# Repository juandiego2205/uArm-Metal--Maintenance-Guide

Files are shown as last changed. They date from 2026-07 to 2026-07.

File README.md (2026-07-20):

# uArm Metal – Maintenance Guide Resources

<table>
<tr>
<td width="220" align="center">

uArm Metal

</td>
<td>

This repository contains the resources used to support the maintenance, calibration, and assembly of the **uArm Metal** robotic arm. It includes the original CAD files, assembly documentation, calibration tools, technical documents, and useful reference links required to work with the platform.

</td>
</tr>
</table>

## Repository Structure

```
uArm_Metal/
├── Assembly_Resources/
├── CAD_Files/
├── Calibration_Files/
├── Documentation/
├── Useful_Links.txt
└── README.md
```

### Assembly_Resources

Contains all resources related to the assembly of the robotic arm.

* Assembly manual
* Assembly videos

### CAD_Files

Contains the original mechanical design files of the uArm Metal.

* STEP files
* STL files
* Assembly files

These files can be used for visualization, modification, manufacturing, or replacement of mechanical components.

### Calibration_Files

Contains the files required to calibrate the robotic arm.

* Arduino calibration
* Calibration data (Excel)

The calibration code requires the official **UArmForArduino** library before compilation.

### Documentation

Contains technical documentation related to the uArm Metal.

Examples include:

* Technical documentation
* Additional reference documents

### Useful_Links.txt

Contains links to official resources and documentation, including:

* Official uArm Arduino library
* Official documentation
* Additional reference pages

## Requirements

To use the calibration software, install the official **UArmForArduino** library before compiling the Arduino project.

## Purpose

This repository serves as a centralized collection of resources for users who need to assemble, maintain, calibrate, repair, or study the **uArm Metal** robotic arm. It is intended to simplify access to all relevant documentation, software, CAD models, and supporting materials in a single location.

## License

The original files, documentation, and software remain subject to the licenses and copyrights of their respective authors. This repository organizes and references these materials for educational, maintenance, and research purposes.

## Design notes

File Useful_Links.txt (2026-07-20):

uArm Resources
===============

Official Arduino Library
https://github.com/uArm-Developer/UArmForArduino

uArm Metal Getting Started Guide
https://uarmdocs.readthedocs.io/getting_started/

Arduino Library Documentation
https://uarm-developer.github.io/UArmForArduino/

Description:
- Official Arduino library for the uArm Metal.
- User guide for hardware setup, calibration, and operation.
- API documentation and programming reference.

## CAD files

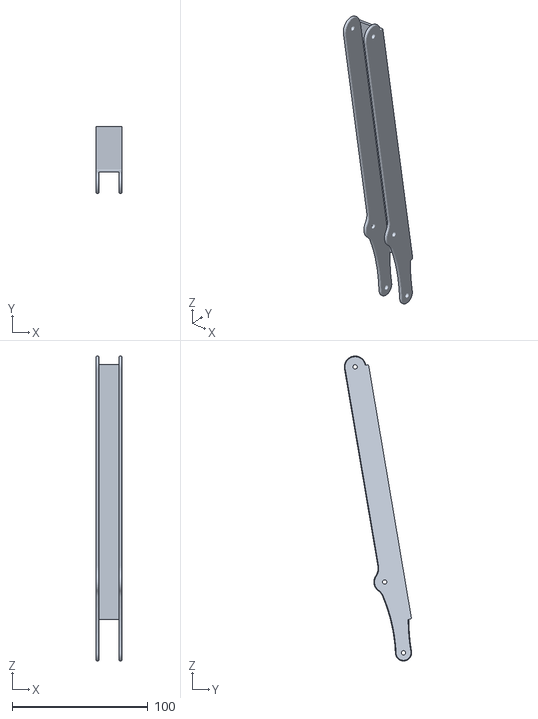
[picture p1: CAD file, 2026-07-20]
CAD_Files/STL_files_Uarm(metal)/Uarm metal 装配体 - U100002_ASM-1 U200004_ASM-1 U200004-1.STL
19.0 x 49.6 x 224.7

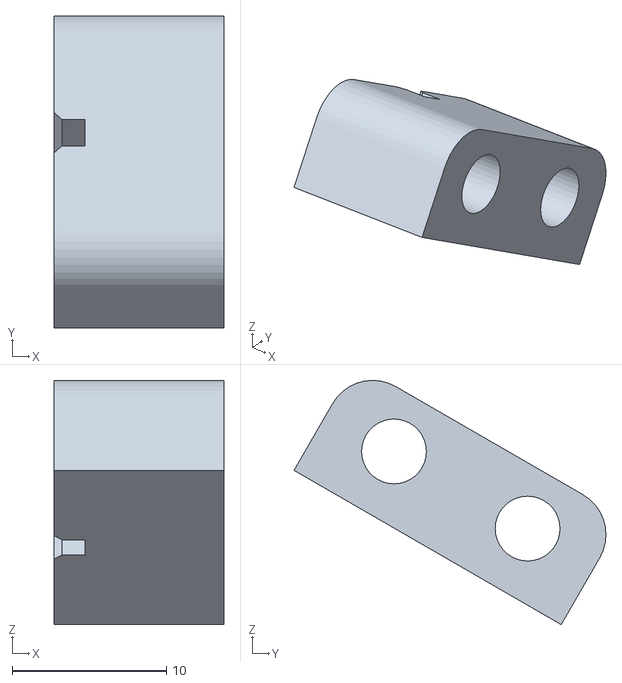
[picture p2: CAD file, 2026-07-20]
CAD_Files/STL_files_Uarm(metal)/Uarm metal 装配体 - U100002_ASM-1 U200040_ASM-1 U200040-1.STL
11.0 x 20.2 x 15.8

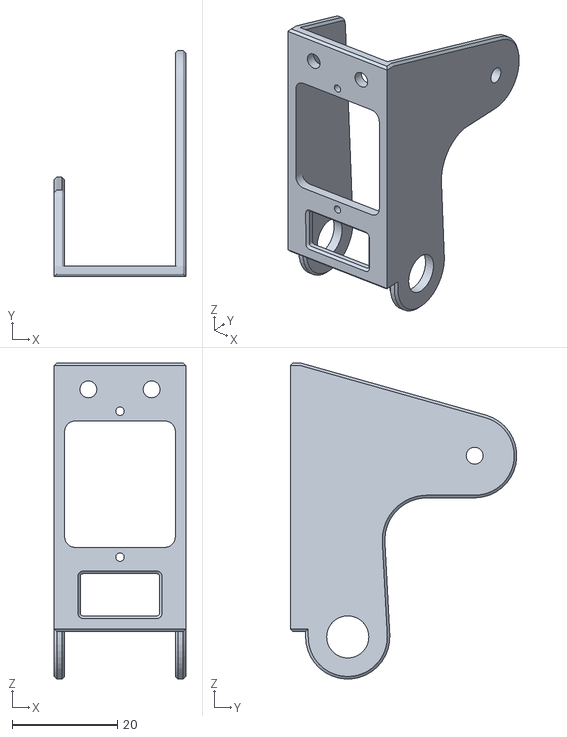
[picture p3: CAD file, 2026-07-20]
CAD_Files/STL_files_Uarm(metal)/Uarm metal 装配体 - U100002_ASM-1 U200003_ASM-1 U200003-1.STL
25.0 x 43.0 x 60.0

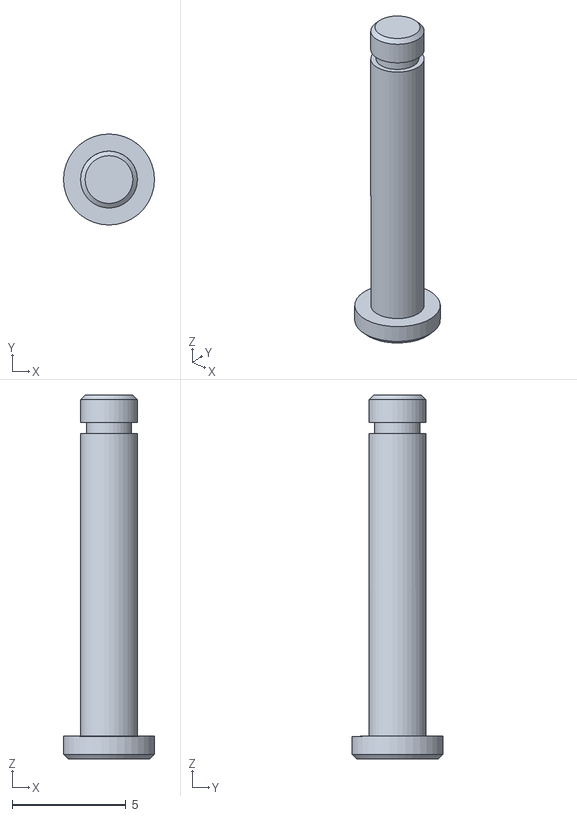
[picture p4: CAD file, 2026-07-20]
CAD_Files/STL_files_Uarm(metal)/Uarm metal 装配体 - U100004_ASM-1 U300004_ASM-1 U200036_ASM-1 U200036-1.STL
4.00 x 4.00 x 16.0

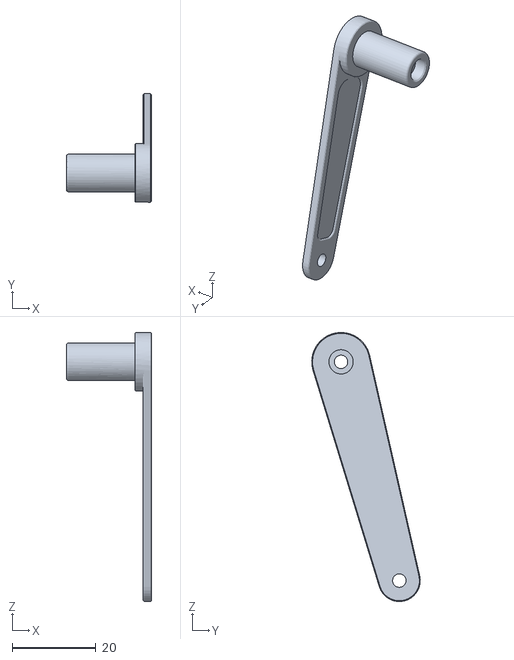
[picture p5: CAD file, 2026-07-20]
CAD_Files/STL_files_Uarm(metal)/Uarm metal 装配体 - U100002_ASM-1 U200067_ASM-1 U200067-1.STL
20.3 x 25.9 x 64.2

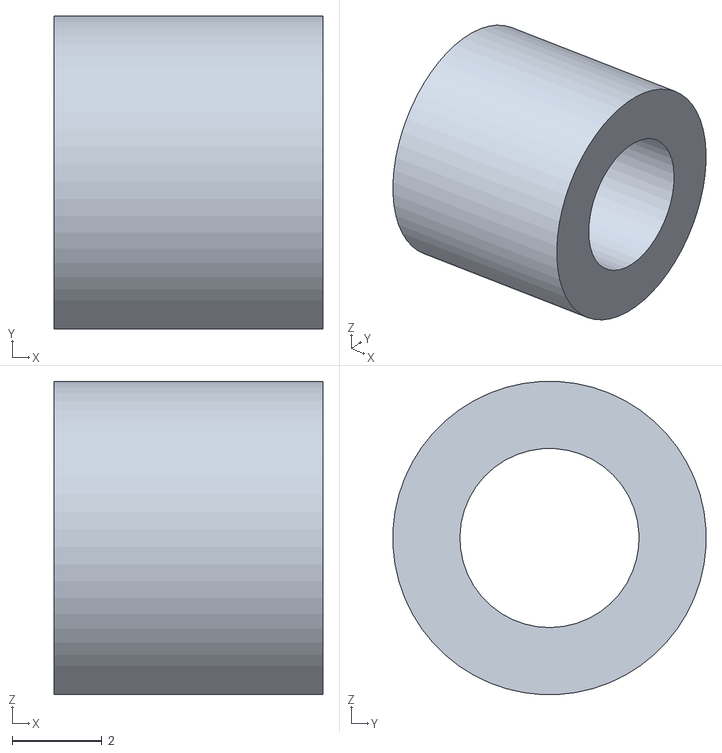
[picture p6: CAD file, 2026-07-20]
CAD_Files/STL_files_Uarm(metal)/Uarm metal 装配体 - U100002_ASM-1 U200020_ASM-1 U200020-1.STL
6.00 x 6.99 x 6.99

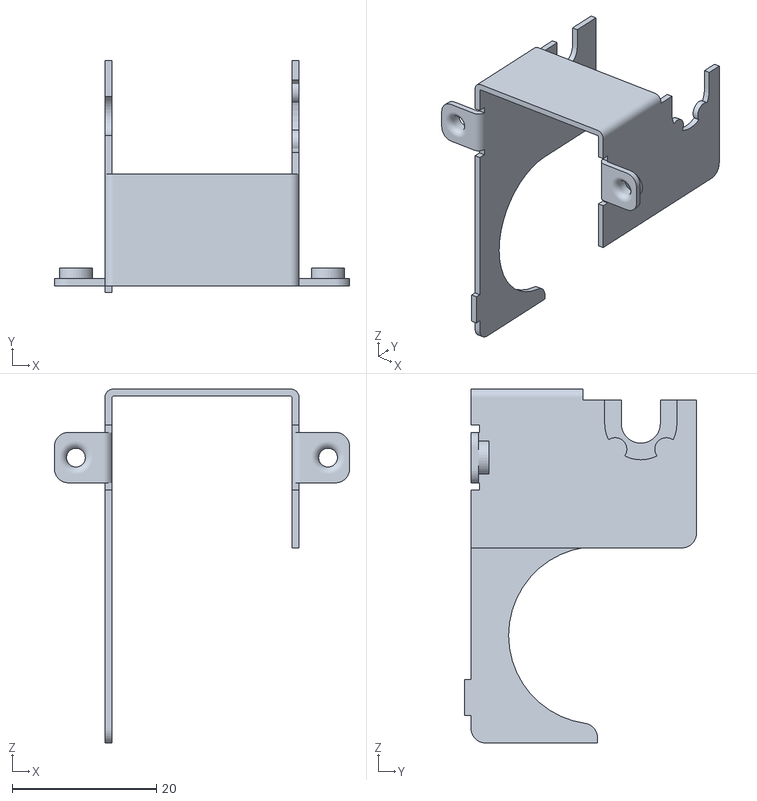
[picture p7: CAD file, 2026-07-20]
CAD_Files/STL_files_Uarm(metal)/Uarm metal 装配体 - U100003_ASM-1 U300002_ASM-1 U200030_ASM-1 U200030-1.STL
40.9 x 32.1 x 49.0

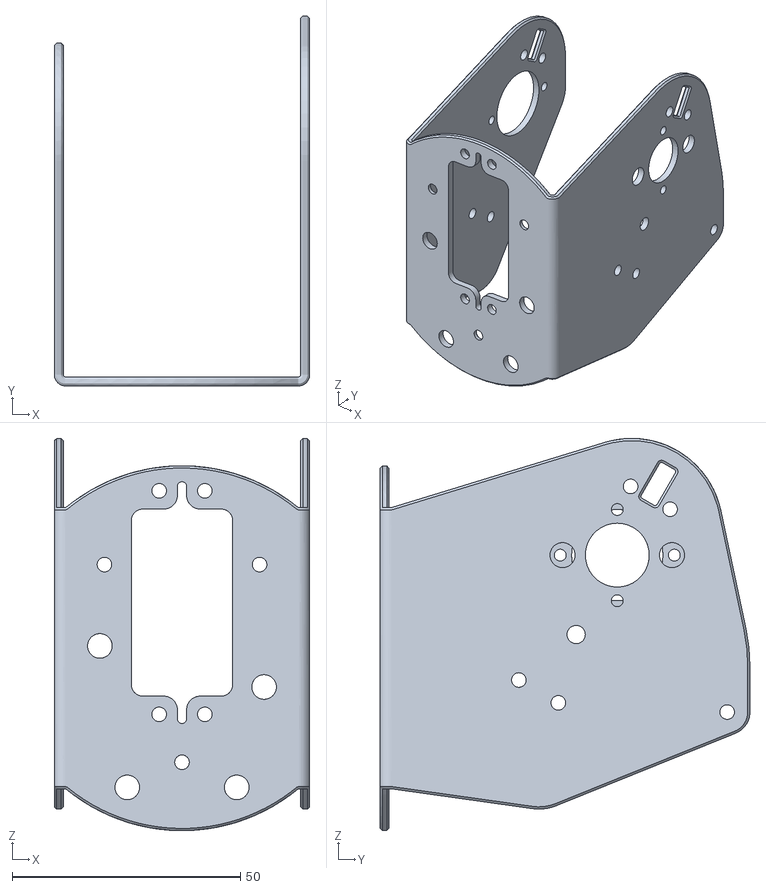
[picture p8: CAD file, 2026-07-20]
CAD_Files/STL_files_Uarm(metal)/Uarm metal 装配体 - U100002_ASM-1 U200021_ASM-1 U200021-1.STL
56.0 x 81.1 x 86.0

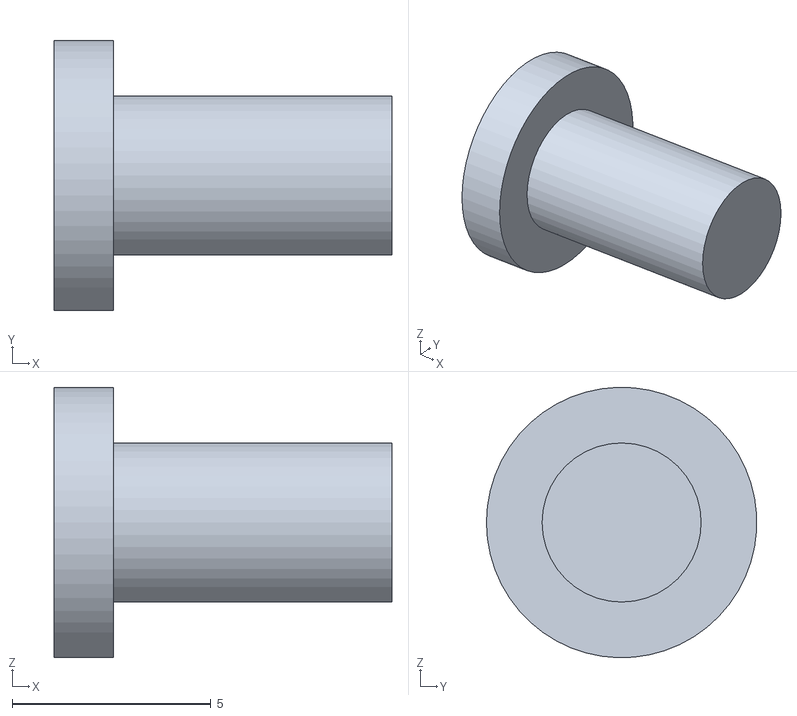
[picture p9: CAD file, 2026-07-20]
CAD_Files/STL_files_Uarm(metal)/Uarm metal 装配体 - U100002_ASM-1 U400001-7.STL
8.50 x 6.79 x 6.80

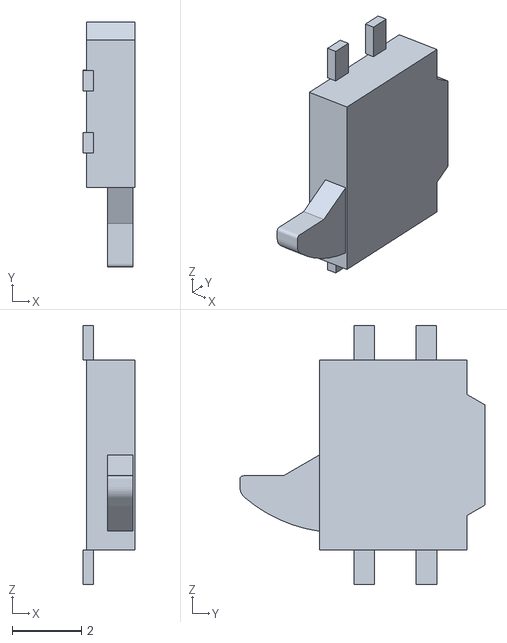
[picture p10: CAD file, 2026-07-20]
CAD_Files/STL_files_Uarm(metal)/Uarm metal 装配体 - U100004_ASM-1 U910001_ASM-1 SW1AB_420_33T35-1.STL
1.50 x 7.10 x 7.50

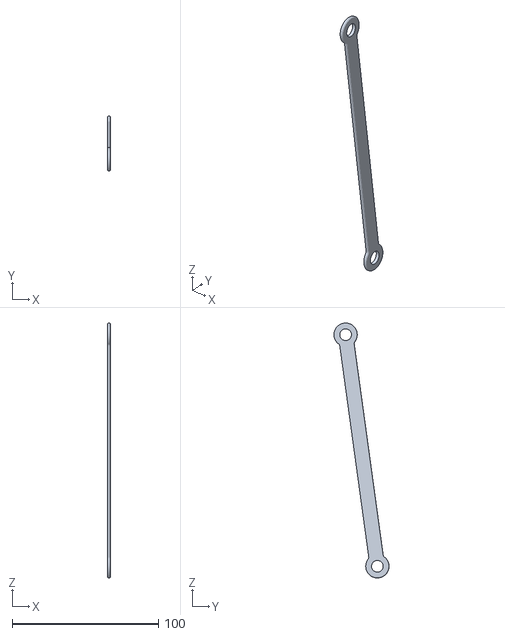
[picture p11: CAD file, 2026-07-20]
CAD_Files/STL_files_Uarm(metal)/Uarm metal 装配体 - U100002_ASM-1 U200011_ASM-1 U200011-1.STL
2.00 x 37.7 x 174.5

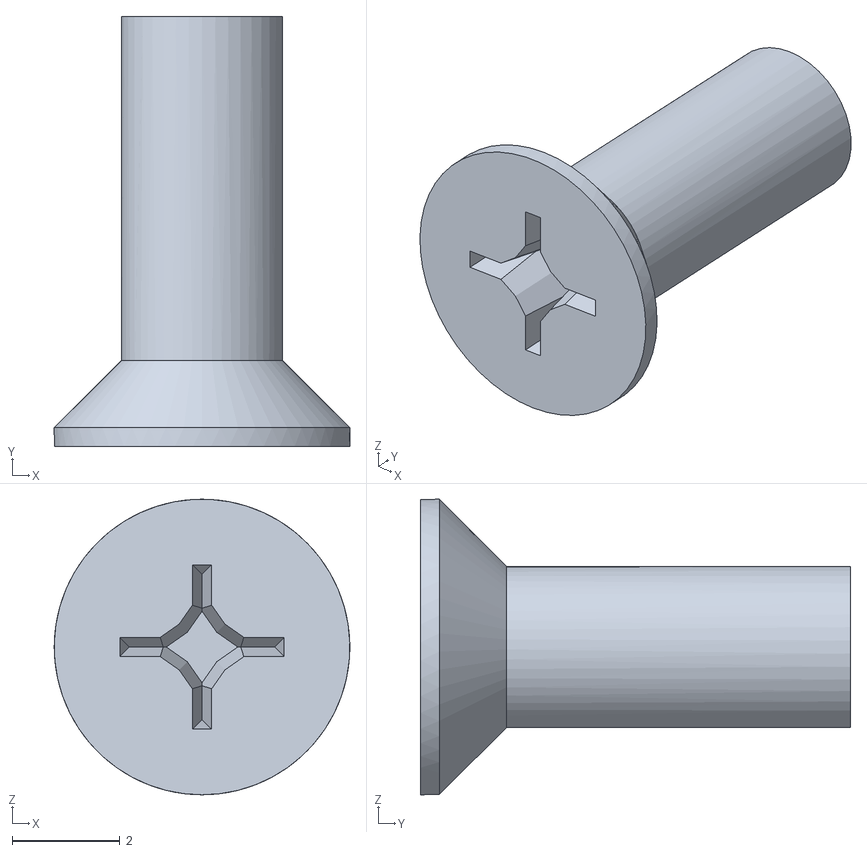
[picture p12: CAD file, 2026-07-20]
CAD_Files/STL_files_Uarm(metal)/Uarm metal 装配体 - U100002_ASM-1 GBT819M3X8-5.STL
5.50 x 8.00 x 5.50

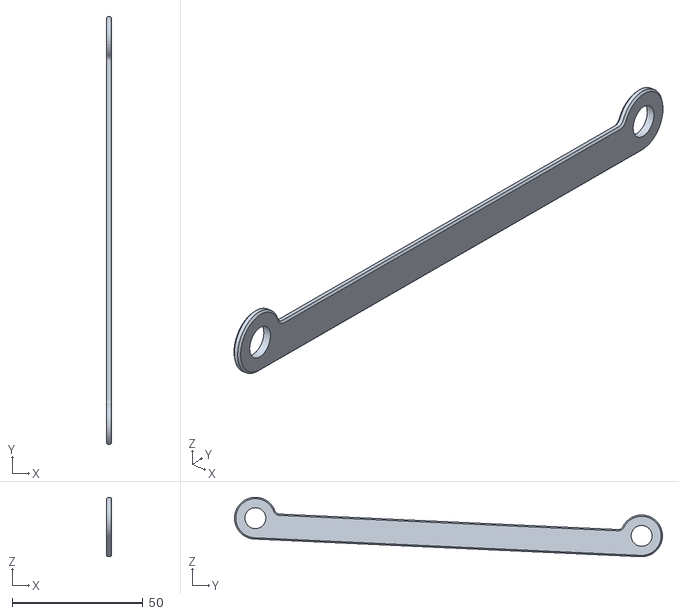
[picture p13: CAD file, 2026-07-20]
CAD_Files/STL_files_Uarm(metal)/Uarm metal 装配体 - U100002_ASM-1 U200013_ASM-1 U200013-1.STL
2.00 x 163.8 x 22.7

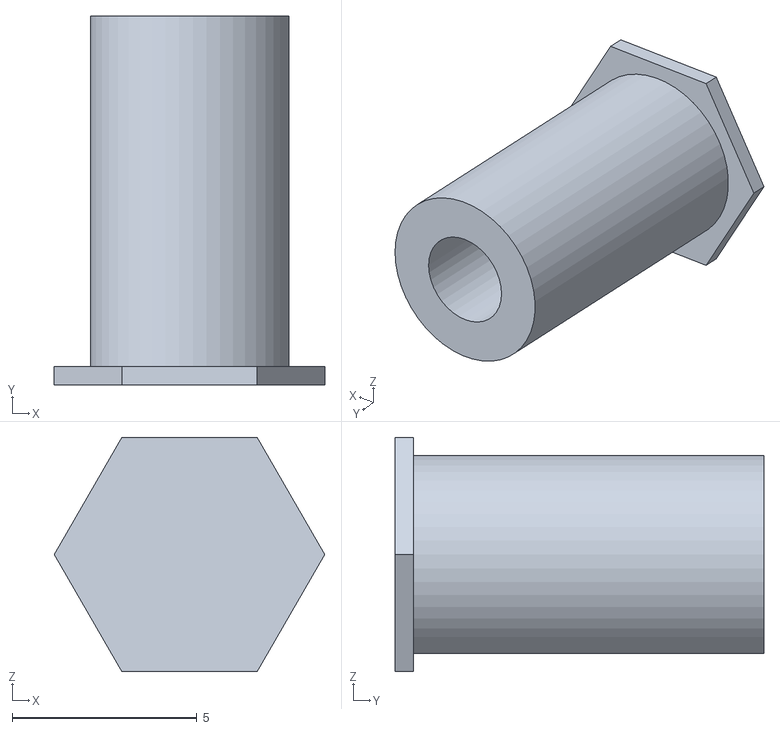
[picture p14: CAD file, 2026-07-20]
CAD_Files/STL_files_Uarm(metal)/Uarm metal 装配体 - U100002_ASM-1 U200021_ASM-1 SOO-3_5M3-10-2.STL
7.33 x 10.0 x 6.35

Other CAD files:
CAD_Files/STL_files_Uarm(metal)/Uarm metal 装配体 - U100002_ASM-1 U200012_ASM-1 U200012-1.STL
CAD_Files/STL_files_Uarm(metal)/Uarm metal 装配体 - U100002_ASM-1 GBT819M3X8-4.STL
CAD_Files/STL_files_Uarm(metal)/Uarm metal 装配体 - U100002_ASM-1 U200022_ASM-1 U200022-1.STL
CAD_Files/STL_files_Uarm(metal)/Uarm metal 装配体 - U100002_ASM-1 U200040_ASM-2 U200040-1.STL
CAD_Files/STEP/Base_Card.step
CAD_Files/STEP/Base_Connector.step
CAD_Files/STEP/Base_Connector_Card.step
CAD_Files/STEP/Base_Connector_Servo.step
CAD_Files/STEP/Base_Link_Right.step
CAD_Files/STEP/Base_Plate.step
CAD_Files/STEP/Base_Protector_Left.step
CAD_Files/STEP/Base_Protector_Right.step
CAD_Files/STEP/Base_Support_Left_and_Right.step
CAD_Files/STEP/Base_arm_left.step
CAD_Files/STEP/Box_Cover_Pump.step
CAD_Files/STEP/Box_Pump.step
CAD_Files/STEP/Connector_Link_Left.step
CAD_Files/STEP/Connector_side.step
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

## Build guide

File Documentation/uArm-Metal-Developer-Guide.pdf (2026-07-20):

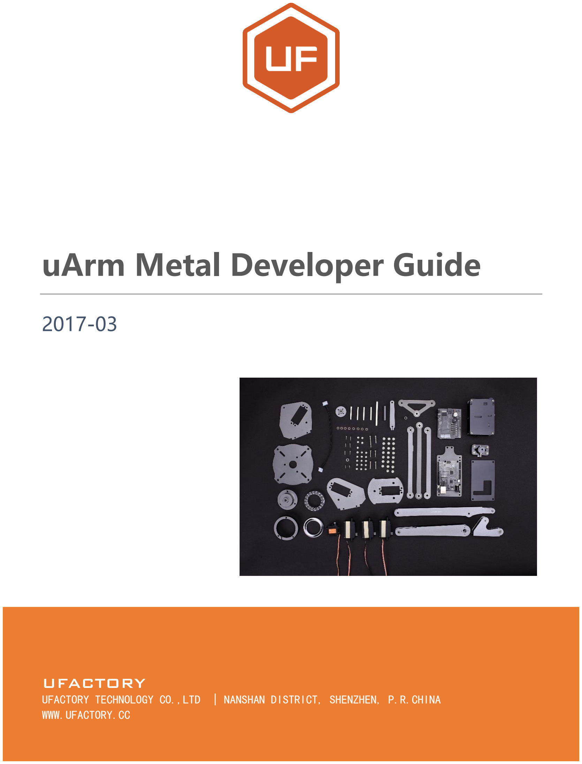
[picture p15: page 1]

UFACTORY TECHNOLOGY CO.,LTD | NANSHAN DISTRICT, SHENZHEN, P.R.CHINA
WWW.UFACTORY.CC

# uArm Metal Developer Guide

2017-03

Addr:NANSHAN DISTRICT, SHENZHEN, P.R.CHINA | Tel：0755-23301959

# Contents

## Introduction

Maybe now you are a

Software Engineer

Mechanism Engineer

Electronic Engineer；

Maybe now you are studying the

Artificial Intelligence

the Computer Science the

Machine Learning；

Maybe now you are A

Scientist

An Artist；

Anyway, if you are reading this Guide-

You are a developer who has interest in ROBOTICS!

We are here to help you build your creative, fun, smart robot ideas come true with uArm! MAKERS COME

FROM ALL JACKS OF LIFE, SO DO UARM MASTERS!

## Software

### Software Installation

UFACTORY provide a link for you that you can download all documents about uArm Metal:

https://drive.google.com/open?id=0B-L-tCvknXU9bUpPbEp5Ry1SYXM

### 1. Basic Software Installation

Please refer to Getting Started Guide.

### 2. Developer Software Installation

Windows

As Python is not defaulted inside of Windows, if you want to use these developing tools, please DOWNLOAD and

INSTALL Python first.

Next, please install pip. We recommendpip-for-windows.

Now you can install uArm' tool kit by sending the command - pip install pyuarm.

Mac

What you need:

Pip -avrdude

Strongly recommend to use this, because it is a really very convenient tool that you type only one install

command:

This command will help you with the installation and very efficient:)

bash -c "$(curl -fsSLhttp://download.ufactory.cc/tools/macosx/install.sh)"

If you would like to install by yourself, you can do so:

First, install pip - sudo easy_install pip

Next, install pyuram - pip install pyuarm

If you need to upgrade the firmware, you need to install avrdude

-refer to Homebrew, a quick and easy way to make it.

Completing homebrew, you can start brew install avrdude.

Linux

What you need:

pip -avrdude

Youcan use the installationtool in the released version of Linux,for example, in the debain, you can just use:

sudo apt-get install python-pip python-dev build-essentialavrdude

After installation, you can use: - pip install pyuarm installation tools.

### Source Code and API Documentation

arduino IDE：https://www.arduino.cc/en/Main/Software

PLEASE DO NOT download your Arduino IDE from https://www.arduino.org , because you may not be able to use that. We recommend Arduino IDE V1.6.12 or later.

arduino API：http://uarm-developer.github.io/UArmForArduino/index.html

Python API：http://pyuarm.readthedocs.io/en/latest/

Pyuarm API：https://pypi.python.org/pypi/pyuarm

uArm protocol：https://github.com/uArm-Developer/UArmForArduino/blob/master/PROTOCOL.md

Arduino UNO board intro：https://www.arduino.cc/en/Main/ArduinoBoardUno?setlang=cn

uArm Metal 3D document：https://grabcad.com/library/uarm-metal-1

### Communication Protocol

uArm Metal’s Communication Protocol

We write uArm’s Communication Protocol in order to help you program with your preferred languages at PC.

Once you send the command (via uArm Protocol), it will automatically analyze it and act as related. If you would

like to write your own uArm protocol for communication, please refer to our communication Protocol on guithub.

### Calibration

Why calibration?

The analog data ADC adopted is not accurate, what's more, the inaccuracy of analog data is different from each

other, so we need to conduct the liner calibration once.
How to calibrate by yourself?

It was calibrated before sale.

1. Please DON'T calibrate it if not necessary. All uArms were calibrated by us before sale. Frequent calibration

will cause damage to theuArm.

2. If you have to calibrate, Please use uarmAssistant，function Re-calibration.
3. uarmAssistant is limited to the purchase of uArm users before April 2016, after April 2016, the user

does not have calibration problems, DO NOT DO THIS STEP.

## Hardware

### uArm Metal Body

### Basic Information of uArm Metal Body

Work Range

You might have guessed the work range with the Limits of XYZ, and the work range for uArm is not a regular area.

However, you might not know there are somewhere which is out of the work range, so we have set restrains for

those places which uArm cannot reach, and return an Error. WorkRangeDiagramofuArm

Work Range PIC 1

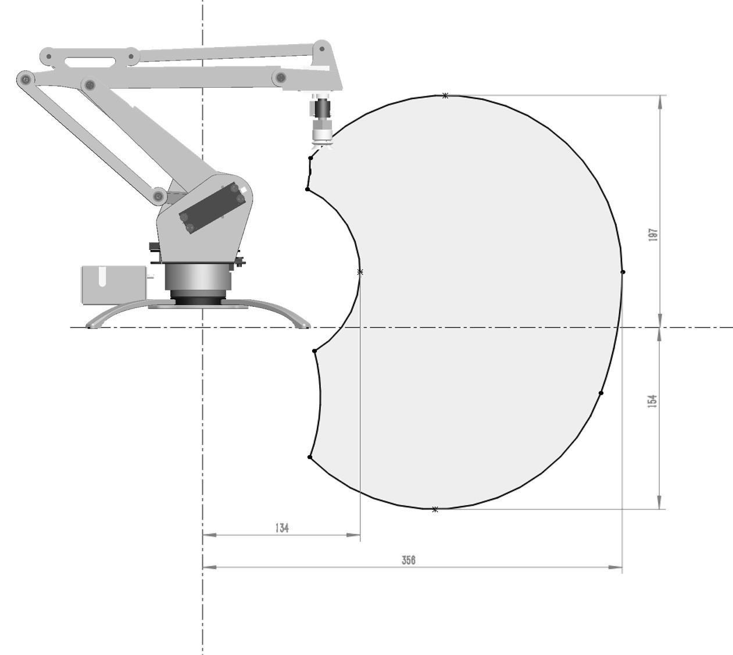
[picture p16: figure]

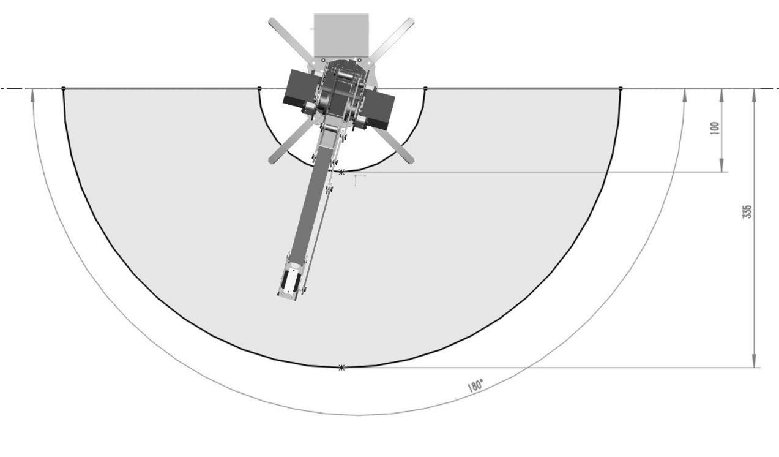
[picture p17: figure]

Work Range PIC2

Accuracy and Offset

Theoretically, the offset is around ±0.5CM. In fact, the range is related with the payload for uArm. Servo has less

offset when working in the range between 40° and 140°; but when it is less than 40° or greater than 140°, the

offset will become wider.

So, please control the payload, don’t make uArm work out of its range, and pay attention not to push servo

working a wide range beyond its limit.

Three Dimension coordination

We use mathematical model- Three Dimension Coordination to describe uArm’s work range. Please refer to

the pic below Dimension Diagram

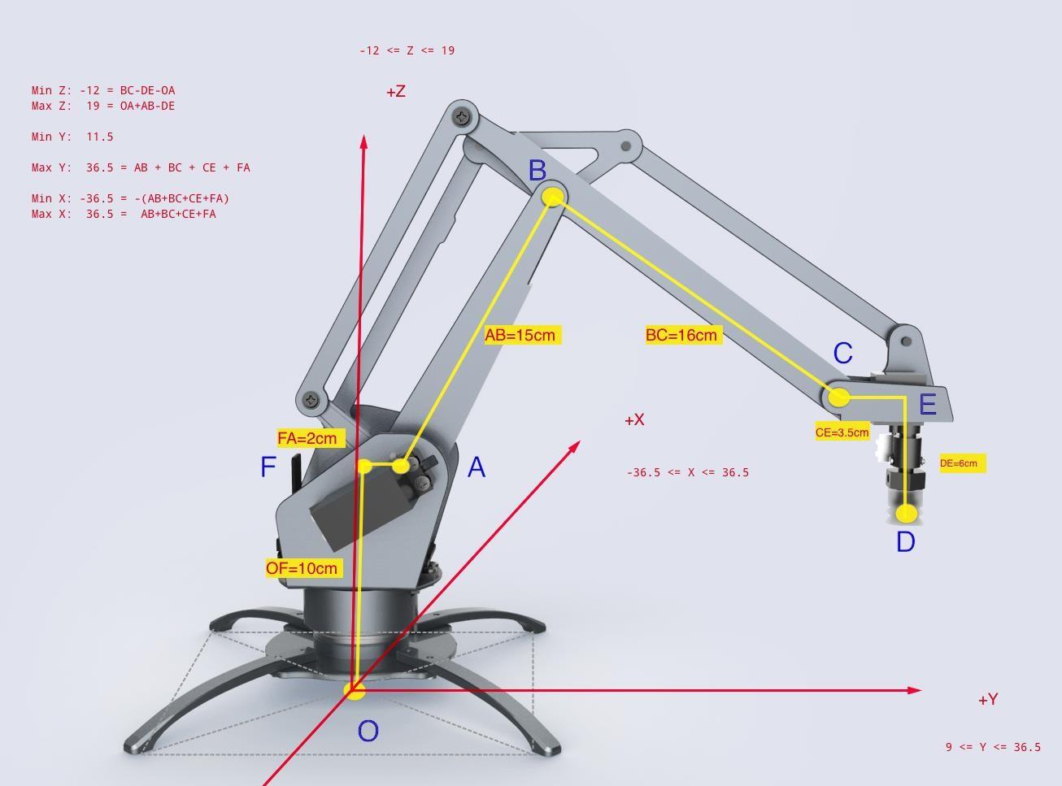
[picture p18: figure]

PIC Three Dimension Diagram

1) PointofJunction

O Original Point (0,0,0)

A The middle point of Left/ Right Axis

B The middle point between two screws--each screw is correspondently on one side of Link 2 as the linkage of

Point B.

C The middle point between two screws-- each screw is correspondently on one side of Link 2 as the linkage of

Point C.

D The Center Point on the bottom of Suction Cup.

E It is an interaction of DE and CE, which are perpendicular to each other. Like in the picture, DE is paralleled

with coordinate axis Z and CE is paralleled with coordinate axis Y.

F It is an interaction of OF and AF, which are perpendicular to each other. Like in the picture, OF is paralleled with coordinate axis Z and AF is paralleled with coordinate axis Y.

2) Line

OA Distance of Original Point O to the center of L/R axis A

OF = 10CM Shadow of OA on coordinate axis +Z AF = 2CM

Shadow of OA on coordinate axis +Y AB = 14.8 CM Length

of Link2

BC = 16CM Length of Link1

CE = 3.5 CM Length of Front Part

DE = 6CM Length of Suction Cup

Extreme/Limits = [-36.5cm ~ 36.5cm]

Max X = AB + BC + CD + AF [Y] =

[11.5 cm ~ 36.5cm] MIN Y = Min Y

Max Y = Max X

[Z] = [-12cm ~ 19cm] Max

Z = OA + AB -DE Min Z = BC

- DE – OA

### uArm metal Specifications

### 1. Apply Environmental Condition

No. | Item | Specification
1.1 | Storage Temperature Range | -20°C～70°C
1.2 | Operate Temperature Range | 0°C～30°C

### 2. Standard Test Environment

No. | Item | Specification
2.1 | Temperature Range | -1 0°C～ 60°C
2.2 | Humidity Range | 65%±1 0%

### 3. Mechanical Specification

No. | Item | Specification
3.1 | Size | 300*270*110mm
3.2 | Weight | 1.9kg
3.3 | Material | Aluminum
3.4 | Water Resistance | NO
3.5 | Repeatability | 10mm(Maximum)
3.6 | Action Radius | 12CM~32CM
3.7 | Max Lifting Weight | 500g (with 15kg
3.8 | Accuracy | 6~10MM (typical)
3.9 | Lifetime | >100000 times

4.Electrical Specification

No. | Item | Specification
4.1 | Operat voltage | DC5V
4.2 | Idle current | 200MA
4.3 | working current | 3.5A

## Board-Arduino

### Board Reference

We use Arduino UNO to modify but have not change the basic working theory. You can learn

from the Arduino Official Webcite, if you are interested.

### Board Pinout

Pic link of pinout (You can refer to “Developer Pack”/Arduino/ PIC of “pinout”.)

### Control Board Diagram

Asfor ControlBoard, please Check the Link here.(You can referto “Developer Pack”/Arduino/

PIC of “uArm-Control Board.)

### Board Specification

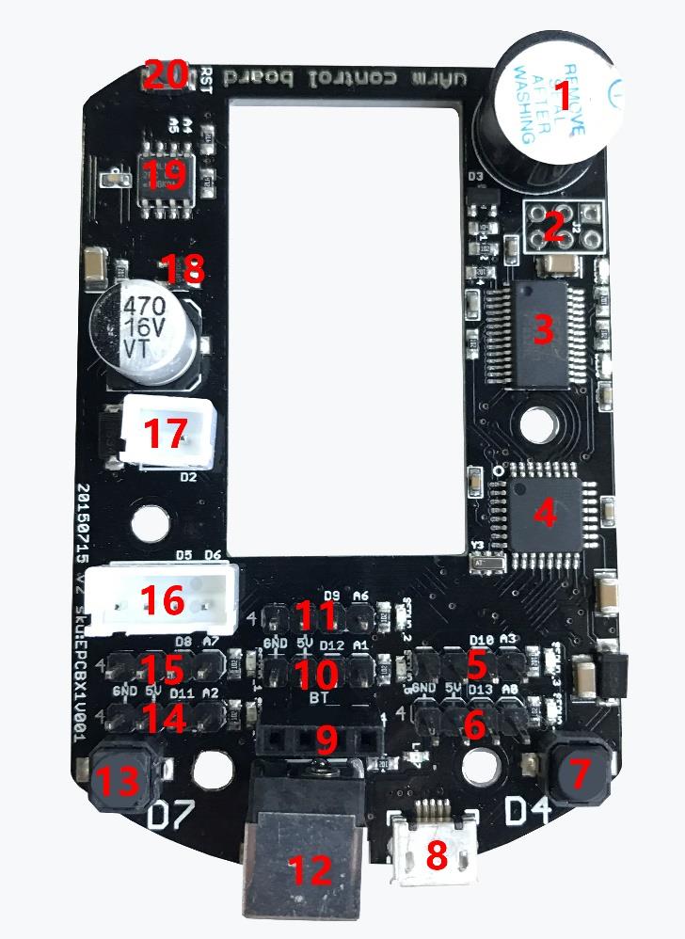
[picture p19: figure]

No. | Item | Description
1 | buzzer | Sound reminder- to remind you the position of uArm, port D3-PD3(INT1).
2 | ISP download port | Starting in the upper left corner in clockwise order: RESET-PC6(RESET)->D13-PB5(SCK)->D12-PB4(MISO)-> VCC(+5V)-> D11-PB3(MOSI)->GND; PB/PC Port is in the ATmega328p.
3 | USB converts to Serial port | Online debug; communication-FT232RL
4 | ATmega328p | - Master chip

5 | Servo 3 Connector (Control the arm end of the servo) | From Left to Right: GND->VCC(+5V)->D10- PB2(SS)->A3-PC3(ADC3); D10 is PWM output and A3 is analog input.
6 | Servo 1 Connector (Control the left servo) | From Left to Right: GND->VCC(+5V)->D13-PB5(SCK)->A0-PC0(ADC0); D10 is PWM output and A3 is analog input.
7 | Switch D4-PD4(T0) | uArm condition exchange.
8 | MINIUSB-A | Download software and in-out communication.
9 | Bluetooth port | From Left to Right: D1-PD1(TXD)->D0-PD0(RXD)->VCC(+5V)->GND; uArm condition and specification setting and operation.
10 | Servo 0 Connector (Control the base servo) | From Left to Right: GND->VCC(+5V)->D12-PB4(MISO)->A1PC1(ADC1); D12 is PWM output and A1 is analog input.
11 | Servo Connector (Control the electric griper) | From Left to Right: GND->VCC(+5V)->D9-PB1(OC1)->A6-(ADC6); D9 is PWM output and A6 is analog input.
12 | Power | 5V power adapter and input currency >5A
13 | Switch D7-PD7(AIN1) | Change uArm condition.
14 | Servo 2 Connector (Control the right servo) | From Left to Right: GND->VCC(+5V)->D11- PB3(MOSI)->A2-PC2(ADC2); D11 is PWM output and A2 is analog input.
15 | Servo connector（preserved） | From Left to Right: GND->VCC(+5V)->D8- PB0(ICP)->A7-(ADC7); D8 is PWM output and A7 is analog input.
16 | Pump connector | From Left to Right: GND->VCC(+5V)->D8- PB0(ICP)->A7-(ADC7). D8 is PWM output and A7 is analog input.
17 | End suction tip limit switch interface | From Left to Right: GND->D2
18 | LDO | 5V transfer 3.3V
19 | EEPROM External power-down memory | 64KB
20 | Reset

## Servo

### Basic Information of Servo

### Servo Schematics

When we talk about the servo control, we have to mention Arduino. Thanks to Arduino, we can have

thousand open sourced libraries. For uArm, our servo motor supports

Arduino's servo.h library.

### Servo Attach/Detach

Before using servo, it is a must to attach servos. At this time, servos will be locked.

### Rotation Ranges of Servo

We use default functionsforservo servoWrite(). The unit of itsrotation is degree, ranging from 0 to 180.

When assembling, we install the servo to uArm with a fixed angle.

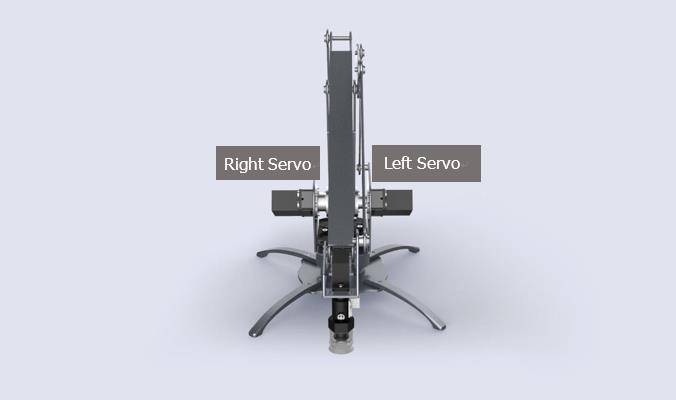
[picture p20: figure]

The servo on the left can range from 0° to 150° and the one on the right is 20° to 150°.

Now you can control the movement of uArm by read the servo's angle, but this is not visible, and somehow

dangerous. Because the linkage of servos may lock each other, it is a factor lead to burn the servo. We would

like to suggest you to construct a three dimension coordination to control uArm’ move.

### Read the servo angle

There is a build-in ADC (analog and digital convertor), which can change the current analog signal into digital

one. And then, with the function analogRead which is defaulted in Arduino, the digital data can be read out

and get the current angle with this

formula intercept + analog * slope.

### Servo Specification

1.Condition

Storage Temperature Range | -20°C～70°C
Operating Temperature Range | -10°C～60°C

2.Mechanism

Size | 40×20×38mm
Weight | 56g
Gear type | metal gear
Limit angle | 210°±5°
Bearing | 2BB
Horn gear spline | 25T
Horn type | Plastic, POM
Case | Engineering plastics(Polyamide)
Motor | DC motor
Splash water resistance | No

### 3. Electric

Horn type | Plastic, POM
Case | Engineering plastics(Polyamide)
Connector wire | 300mm±5mm
Motor | DC motor
Splash water resistance | No

### The definition of port for uArm Metal servo

DM1500A is fully compactable with normal 3 pin port and the forth is used for the output of potentiometer as

positon feedback of uArm.

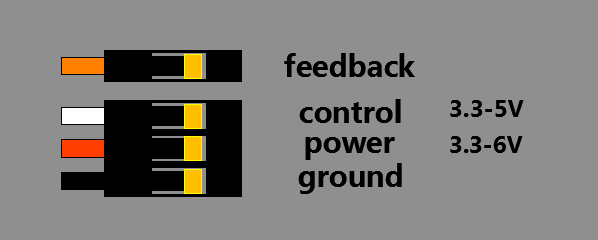
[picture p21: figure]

Voltage and angle

An | Value (TYP)
0° | 0.364V
90 | 1.723V
18 | 3.076V

Ps:1, because of the correspondence-difference of potentiometer inside servo, different

servo might have ±10% difference.

2, Different ADC will leads different sample number when output.

### Control

PWM and specification as following:

Command signal | Pulse width modification
Pulse frequency | 50Hz
Pulse width range | 500～2500usec
Neutral position | 1500usec
Running degree | 180°±3° (when 500～2500usec)
Dead band width | 2 usec
Rotating direction | Clock wise(when 500～2500usec)

When control port is 0°, the oscillo-gram is the pic below (the pic on the right is enlarged

drawing of a single wave).

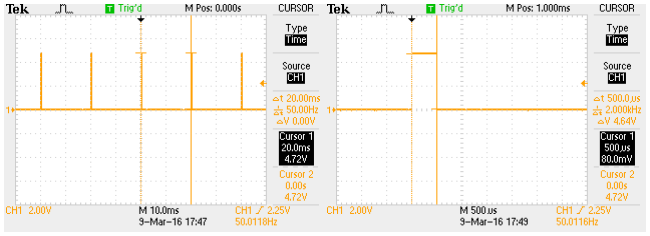
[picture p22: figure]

When control port is 90°, the oscillo-gram is the pic below (the pic on the right is enlarged drawing

of a single wave)

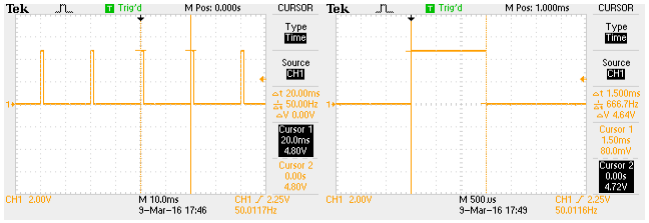
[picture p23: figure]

When control port is 180°, the oscillo-gram is the pic below (the pic on the right is enlarged

drawing of a single wave).

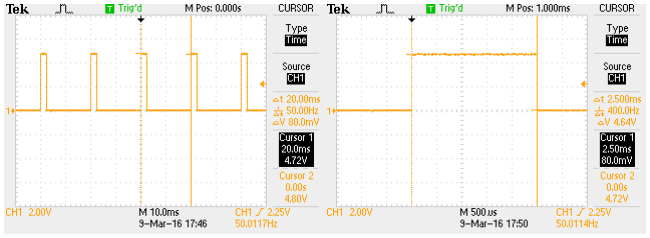
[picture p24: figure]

## Vacuum Pump/mechanical Gripper/ Universal Holder

## Pump

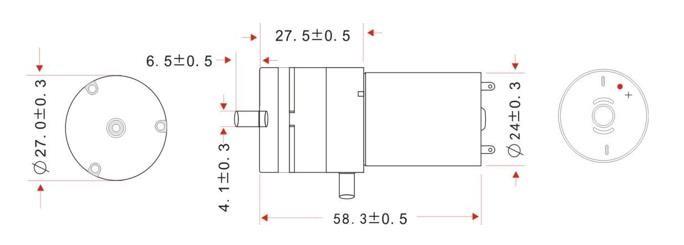
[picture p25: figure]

Voltage：DC 4-5V

Current： <400mA

Reference

### 1. Pump Specification (You can referto “Developer Pack”/Pump/ “Pump Specification”.)

### 2. Pump User Guide(You can refer to “Developer Pack”/Pump/ “uArm Vacuum System

User Guide”.)

Gripper | (You can refer to “Developer Pack”/Gripper/ “gripper user guide”.)
Universal Holder | (You can refer to “Developer Pack”/Gripper/ “holder user guide”.)

## Protection

How to prevent damaging uArm?

Make sure you use ourfirmware and itis updated,the payload and work range is not go beyond of its

limits.

Under what circumstances will the servo be burned or damaged?

1, The payload is out of its limit or work with the load almost its limit for a long time; 2,

The servo is hit hard;

3, Use the wrong power supply, which often burn the servo.

Under what circumstances should I unplug uArm ASAP?

When you see the red light is flashing, which means something wrong already happen, please

unplug ASAP.

## 5．uArm Community

Welcome to the uArm Community! Now,you can explore uArm with the world of robot

enthusiasts,Makers, sartists and scientists!

Official Website：

https://www.ufactory.cc/

Official Forum：

https://forum.ufactory.cc/

Official WeChat Account：

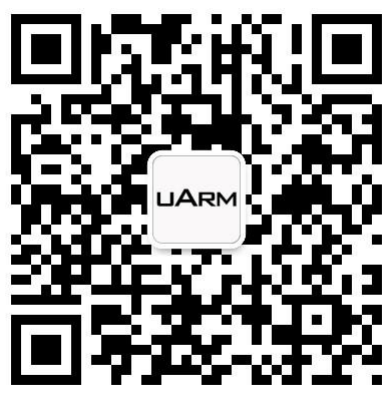
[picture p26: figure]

Official Media：

More Help?

【Contact Us】.

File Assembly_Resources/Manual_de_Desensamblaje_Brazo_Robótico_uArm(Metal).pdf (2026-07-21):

# MANUAL DE DESENSAMBLE

## uArm Metal

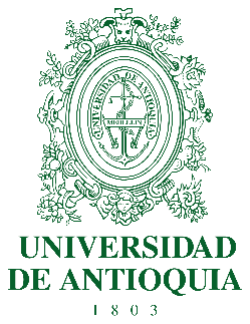
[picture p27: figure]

Universidad de Antioquia - Bioingeniería

Autores: Juan Diego Caguasango

Juan Sañudo

Docente: Juan Diego Lemos

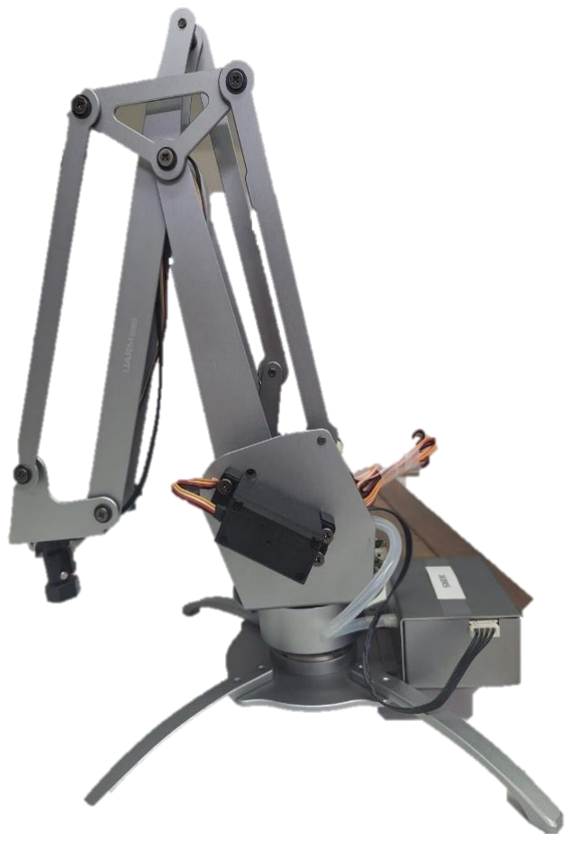
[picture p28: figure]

MANUAL DE DESENSAMBLE uArm Metal (Bioingeniería, Universidad de Antioquia)

### Tabla de contenido

Figura 2. Despiece general del brazo robótico uArm con numeración de referencia de las piezas (ver

Figura 3. Vista complementaria del despiece del uArm con identificación de componentes.(Diseño

Figura 7. Acceso al tornillo central del servomotor derecho a través del orificio dejado por el

Figura 11. Orificios de acceso en el lado izquierdo del mecanismo, utilizados para retirar la pieza de

Figura 12 y 13. Retiro de la pieza que conecta la parte central con la base del brazo robótico (Diseño

Figura 15 y 16. Desarme de la cabeza del brazo robótico (# 17 a #22 de la tabla 1) (Diseño CAD)...8

Figura 20 y 21. Componentes internos del sistema de succión extraídos; desarme finalizado (Diseño

## 1. Descripción general del brazo robótico

El brazo robótico uArm está conformado por una estructura mecánica modular integrada por servomotores, una tarjeta de control y un sistema de succión. La Tabla 1 presenta el listado de los componentes principales utilizados durante los procedimientos de desarmado, indicando la cantidad y el material de fabricación de cada uno. La identificación numérica de estos componentes corresponde a la mostrada en las Figuras 2 y 3, lo que facilita su localización a lo largo del manual. Adicionalmente, se desarrolló un modelo CAD completo del brazo robótico con el fin de facilitar la comprensión de su estructura y del proceso del desmontaje. Al final de este documento se incluye un enlace al repositorio donde se encuentran disponibles el modelo CAD, el video del procedimiento de desarmado, así como la documentación complementaria.

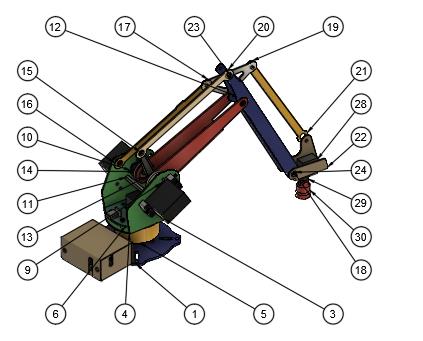
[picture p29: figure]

Figura 2. Despiece general del brazo robótico uArm con numeración de referencia de las piezas (ver Tabla 1). (Diseño CAD).

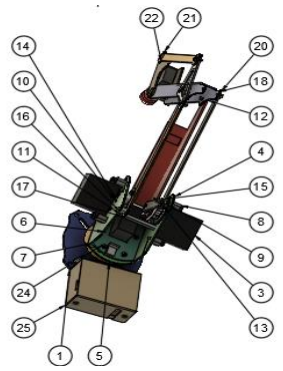
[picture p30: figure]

Figura 3. Vista complementaria del despiece del uArm con identificación de componentes.(Diseño CAD).

Elemento | Cantidad | Número de pieza
1 | 1 | Base_Plate
2 | 1 | Base_Connector_Servo
3 | 3 | Servomotor_Base_Right_Left
4 | 1 | Base
5 | 1 | Base_Connector
6 | 4 | Base_Connector_Card
7 | 1 | Base_Card
8 | 4 | Servo_Connector_Base
9 | 1 | Base_Protector_Left
10 | 1 | Base_Protector_Right
11 | 1 | Standoff_M4
12 | 1 | Base_Support_Left_and_Right
13 | 1 | Right_Connector_Base
14 | 1 | Left_Connector_Base
15 | 1 | Base_arm_left
16 | 1 | Connector_side
17 | 1 | Base_Link_Left
18 | 1 | Left_and_Right_Support_Head
19 | 1 | Connector_Link_Left
20 | 1 | Base_Link_Right
21 | 1 | Left_Link_Head
22 | 1 | Head_Servo_Support
23 | 8 | Screw_GBT819_M3x4
24 | 13 | Screw_GBT819_M3x8
25 | 1 | Box_Pump
26 | 1 | Box_Cover_Pump
27 | 1 | Pump_Support_InsideBox
28 | 1 | Servomotor_Head
29 | 1 | Sensor_pump
30 | 1 | Sensor_pump_FinalPart

Tabla 1. Lista de piezas del brazo robótico uArm.

## 2. Secuencia de desarme

Paso 1. Desconexión eléctrica

Desconecte el cable USB y la fuente de alimentación del uArm. Posteriormente, desconecte los conectores de los servomotores de la placa base para evitar la alimentación del sistema durante el proceso de desarme.

Paso 2. Retiro del Servomotor Izquierdo

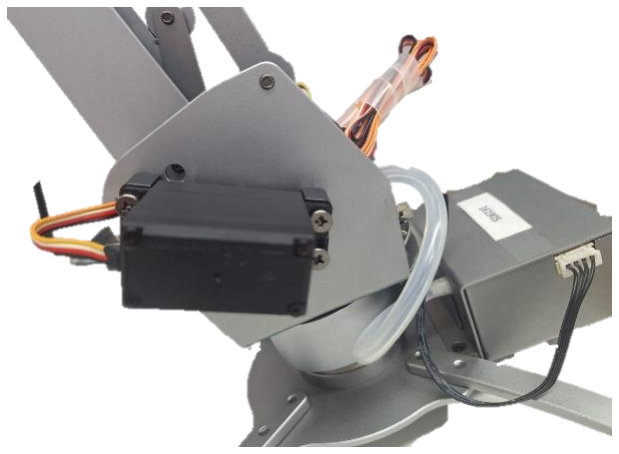
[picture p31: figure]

Figura 4. Tornillos laterales de fijación del servomotor izquierdo antes de su retiro.

El desarme inicia con el retiro del servomotor izquierdo, ya que este componente no está fijado mediante un tornillo central al eje de salida. Para desmontarlo, retire los cuatro tornillos ubicados en los laterales del soporte del servomotor. Una vez retirados, aplique una ligera presión para separar el servomotor del conjunto, evitando movimientos bruscos que puedan dañar el acople o los cables.

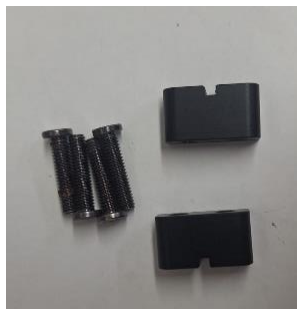
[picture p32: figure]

Figura 5. Piezas de fijación al servomotor izquierdo una vez desmontado (# 8 de la tabla 1).

Paso 3. Retiro del servomotor derecho

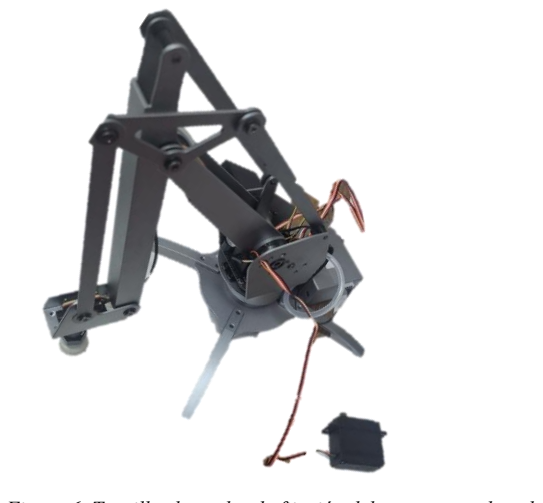
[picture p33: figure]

Figura 6. Tornillos laterales de fijación del servomotor derecho.

Con el servomotor izquierdo desmontado, continúe con el retiro del servomotor derecho. Al igual que en el paso anterior, retire los cuatro tornillos laterales que fijan el servomotor al soporte. A diferencia del servomotor izquierdo, este posee un tornillo central que lo une al eje del mecanismo. Para acceder a dicho tornillo, introduzca un destornillador a través del orificio dejado por el servomotor izquierdo, tal como se muestra en la Figura 7. Una vez retirado el tornillo central, extraiga cuidadosamente el servomotor derecho del conjunto.

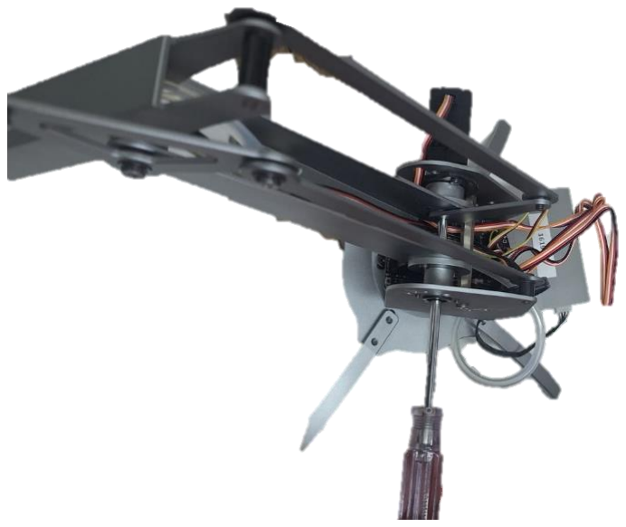
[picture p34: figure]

Figura 7. Acceso al tornillo central del servomotor derecho a través del orificio dejado por el servomotor izquierdo.

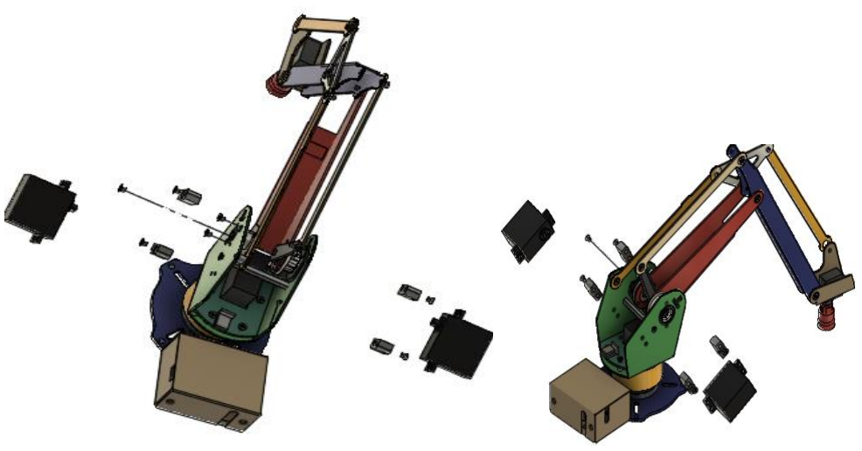
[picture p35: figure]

Figura 8 y 9. Extracción del tornillo central del servomotor derecho, (Diseño CAD).

Paso 4. Desmonte de la barra y conexión central-base

Una vez retirados ambos servomotores, quedan expuestos los tornillos que fijan el standoff central (Standoff_M4) del mecanismo, los cuales se indican en la Figura 10 mediante el recuadro rojo. Retire estos tornillos para liberar el standoff central del conjunto (# 11 de la tabla 1).

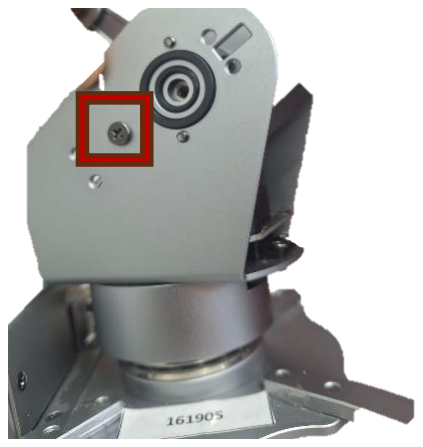
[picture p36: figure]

Figura 10. Tornillos de fijación del standoff central, señalados mediante el recuadro rojo.

Posteriormente, continúe con el desmonte de la pieza de conexión central-base (Left_Connector_Base) que une la parte central con la base del brazo robótico. Para acceder a los tornillos de fijación, utilice los orificios ubicados en el lado izquierdo del mecanismo, los cuales quedaron expuestos tras la retirada del servomotor izquierdo, como se muestra en la Figura 11. Una vez retirados estos tornillos, extraiga cuidadosamente la pieza de conexión.

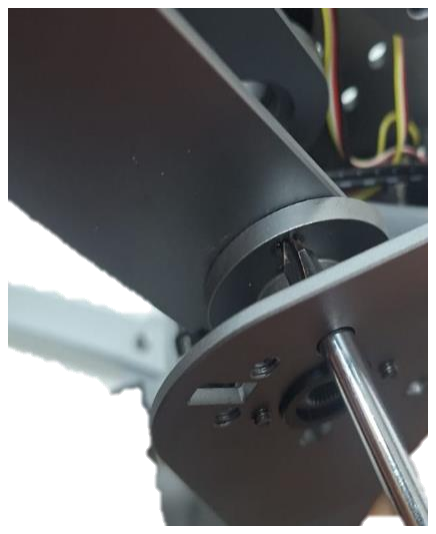
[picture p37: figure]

Figura 11. Orificios de acceso en el lado izquierdo del mecanismo, utilizados para retirar la pieza de conexión central-base (# 14 de la tabla 1).

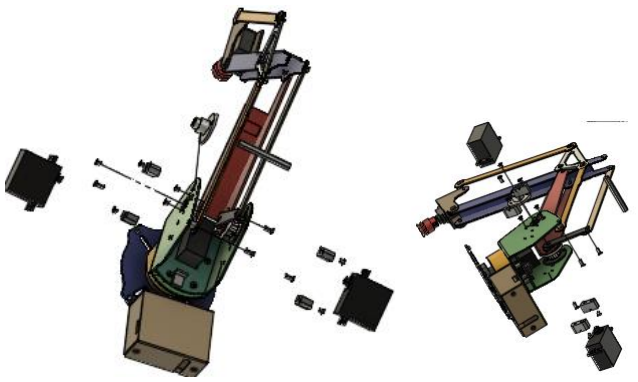
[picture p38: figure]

Figura 12 y 13. Retiro de la pieza que conecta la parte central con la base del brazo robótico (Diseño CAD).

Paso 5. Desarme de las piezas de conexión

Una vez retirada la estructura central, proceda con el desmontaje de todas las piezas de conexión ubicadas en la parte superior del brazo robótico, tal como se muestra en la Figura 14. Retire los tornillos de fijación de cada componente y separe las piezas de manera ordenada para facilitar el posterior proceso de ensamble (# 15 de la tabla 1).

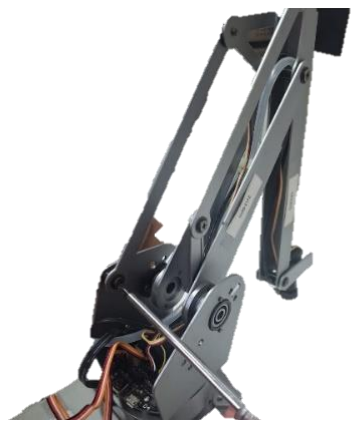
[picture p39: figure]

Figura 14. Piezas de conexión de la parte superior del brazo robótico desmontadas

Posteriormente, continúe con el desarme de la cabeza del brazo robótico. Retire los elementos de fijación que unen el soporte de la cabeza con el eslabón superior y extraiga cuidadosamente los componentes, evitando aplicar esfuerzos excesivos sobre el servomotor o las piezas de soporte. Este paso deja completamente desmontada la estructura mecánica superior del uArm (# 17 a #22 de la tabla 1).

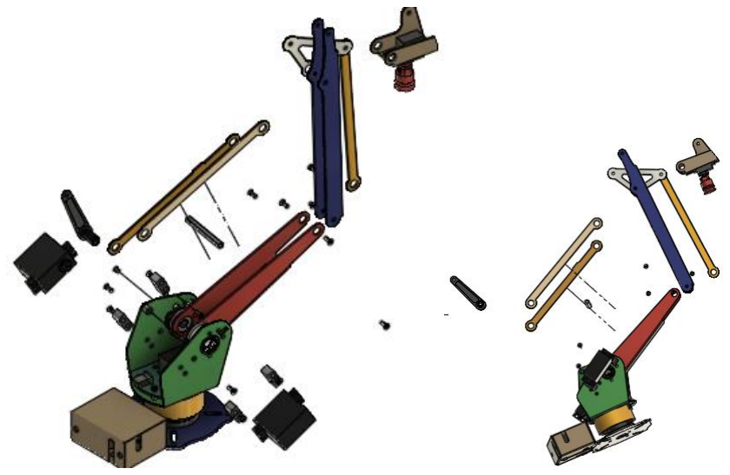
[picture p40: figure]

Figura 15 y 16. Desarme de la cabeza del brazo robótico (# 17 a #22 de la tabla 1) (Diseño CAD).

Paso 6. Retiro del soporte central-base

Una vez desmontadas todas las piezas de conexión y la estructura superior, únicamente queda el soporte central (Base_Support_Left_and_Right) del mecanismo. Debido a que esta pieza se encuentra ajustado a presión, es necesario aplicar una fuerza moderada para desacoplarla del conjunto (# 12 de la tabla 1).

Sujete firmemente la estructura y ejerza una presión uniforme hasta liberar la pieza central, evitando movimientos bruscos que puedan dañar el eje o los componentes adyacentes.

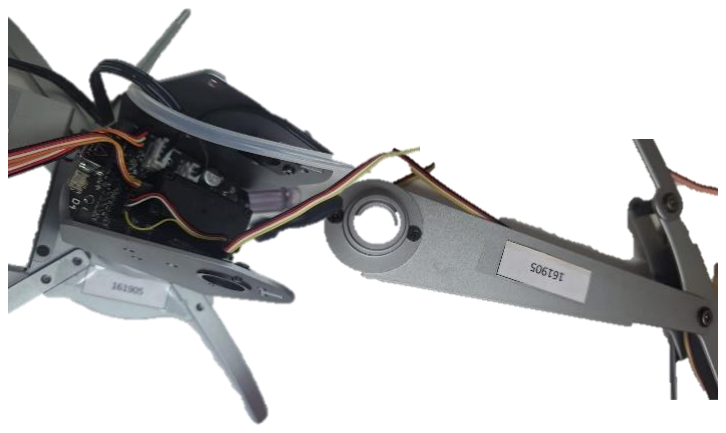
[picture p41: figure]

Figura 17. Retiro del soporte central (Base_Support_Left_and_Right) ajustado a presión.

Paso 7. Retiro de la tarjeta de control y desmonte final

Una vez despejada la zona central del brazo robótico, proceda a retirar la tarjeta de control desatornillando los elementos de fijación que la sujetan a la base (# 7 de la tabla 1). Posteriormente extraiga la tarjeta con cuidado para evitar daños en los conectores. Con la tarjeta retirada, se obtiene acceso al último servomotor de la base. Para desmontarlo, retire el tornillo que fija su eje central, ubicado en la parte inferior del mecanismo, y posteriormente desatornille los cuatro tornillos que sujetan el servomotor a la estructura.

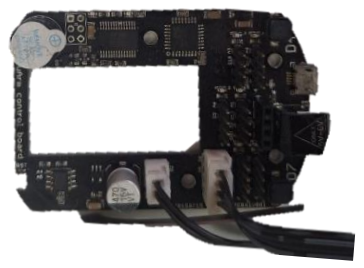
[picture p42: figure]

Figura 18. Tarjeta de control expuesta tras retirar los elementos de fijación.

Finalmente, retire los tornillos de la caja que aloja el sistema de succión y extraiga sus componentes (# 25 de la tabla 1). Con este procedimiento, el desarme del brazo robótico queda completamente finalizado.

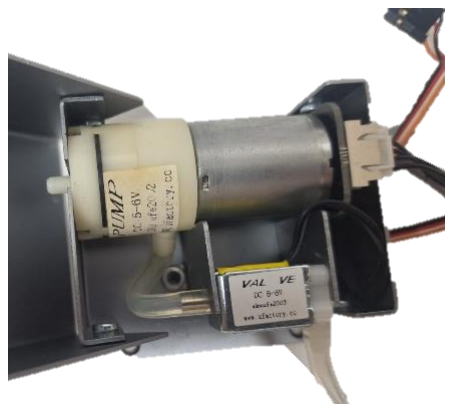
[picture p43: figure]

Figura 19. Bomba de succion vista superior.

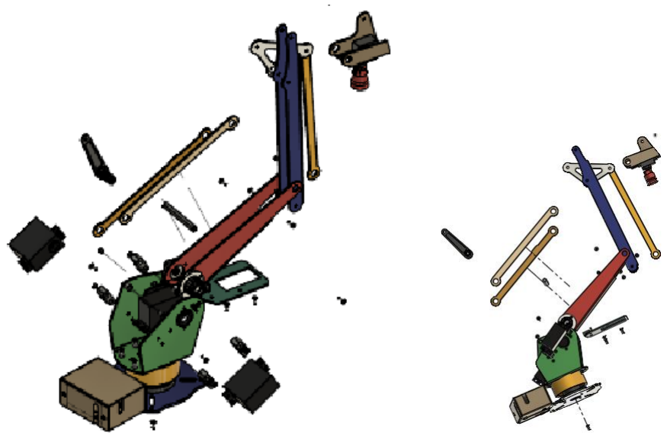
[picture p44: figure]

Figura 20 y 21. Componentes internos del sistema de succión extraídos; desarme finalizado (Diseño CAD).

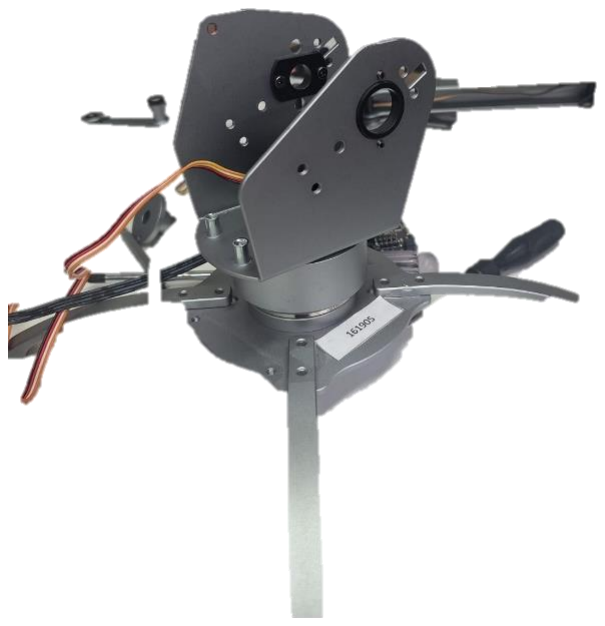
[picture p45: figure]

Figura 22. Visualizacion Desensamble Final

## 3. Anexo

Con el fin de facilitar el acceso a los recursos empleados en este proyecto, se ha dispuesto un repositorio público que reúne toda la documentación técnica relacionada con el brazo robótico uArm. En este repositorio se encuentran disponibles el manual, los modelos CAD, STL, el código fuente, los videos del procedimiento y demás archivos utilizados durante el desarrollo del proyecto.

El repositorio puede consultarse en:

https://github.com/juandiego2205/uArm-Metal--Maintenance-Guide.git

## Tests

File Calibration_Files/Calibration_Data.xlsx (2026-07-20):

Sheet: Calibración
REGISTRO DE CALIBRACIÓN — BRAZOS ROBÓTICOS uArm | Ingeniería de Instrumentación
Revisión de 8 unidades | LEFT_MAX nominal 150° ± 10° | RIGHT_MIN nominal 20° ± 10° | R² ≥ 0.98 excelente
IDENTIFICACIÓN |  |  |  | LÍMITES MECÁNICOS |  |  |  |  |  |  |  |  | RESULTADO FINAL
ID Brazo | Fecha | Ingeniero | Estado General | LEFT MAX (°) | RIGHT MIN (°) | Resultado Límites | Notas Límites | Estado BASE | Estado LEFT | Estado RIGHT | Estado HAND | Estado PUMP | Observaciones | APROBADO
161907 | 2026-06-16 | Juan Caguasango | ✔ OK | 155 | 10 | OK |  | OK | OK | OK | MAL | OK | El Motor hand no se mueve | SÍ | cables ok
1619'5 | 2026-06-16 | Juan Caguasango | #VALUE! | REVISION | REVISION | #VALUE! |  | OK | MAL | OK | REVISON | ok |  | #VALUE!
161908 | 2026-06-17 | Juan Sañudo | ✖ REVISAR | 145 | 65 | FUERA RANGO | EL MOTOR DERECHO NO LLEGA AL RANGO DESEADO | OK | OK | INICIALIZACION | INICIALIZACION | OK | El motor derecho presenta problemas en su ranog y el motor de mano se mueve pero intenta llegar a rangoes que no puedo lo que genera que se fuerce el motor | NO
161906 | 2026-06-17 | Juan Sañudo | ✖ REVISAR | 155 | 79 | FUERA RANGO | EL MOTOR DERECHO NO LLEGA AL RANGO DESEADO | ok | ok | INICIALIZACION | INICIALIZACION | ok | El motor derecho presenta problemas en su ranog y el motor de mano se mueve pero intenta llegar a rangoes que no puedo lo que genera que se fuerce el motor | NO
161894 | 2026-06-17 | Juan Sañudo | ✖ REVISAR | 95 | 90 | FUERA RANGO | EL MOTOR DERECHO E IZQUIERDO NO LLEGAN AL RANGO DESEADO | INICIALIZACION | INICIALIZACION | INICIALIZACION | OK | OK |  | NO
161903 | 2026-06-17 | Juan Sañudo | #REF! |  |  | FUERA RANGO |  | #REF! | #REF! | #REF! | #REF! | #REF! |  | #REF!

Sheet: Resumen Comparativo
RESUMEN COMPARATIVO — PARÁMETROS DE CALIBRACIÓN (8 BRAZOS)
R² ≥ 0.98 = Excelente | R² ≥ 0.95 = Aceptable | R² < 0.95 = Requiere nueva calibración | Offsets |x| ≤ 5° = OK
ID Brazo | LEFT MAX (°) | RIGHT MIN (°) | R² ROT | R² LEFT | R² RIGHT | R² HAND | Off. ROT (°) | Off. LEFT (°) | Off. RIGHT (°) | Off. HAND (°) | Estado General | Aprobado
161907 | 155 | 10 | #REF! | #REF! | #REF! | #REF! | #REF! | #REF! | #REF! | #REF! | ✔ OK | SÍ
1619'5 | REVISION | REVISION | #REF! | #REF! | #REF! | #REF! | #REF! | #REF! | #REF! | #REF! | #VALUE! | #VALUE!
#REF! | #REF! | #REF! | #REF! | #REF! | #REF! | #REF! | #REF! | #REF! | #REF! | #REF! | #REF! | #REF!
161908 | 145 | 65 | #REF! | #REF! | #REF! | #REF! | #REF! | #REF! | #REF! | #REF! | ✖ REVISAR | NO
161906 | 155 | 79 | #REF! | #REF! | #REF! | #REF! | #REF! | #REF! | #REF! | #REF! | ✖ REVISAR | NO
161894 | 95 | 90 | #REF! | #REF! | #REF! | #REF! | #REF! | #REF! | #REF! | #REF! | ✖ REVISAR | NO
161903 | 0 | 0 | #REF! | #REF! | #REF! | #REF! | #REF! | #REF! | #REF! | #REF! | #REF! | #REF!
#REF! | #REF! | #REF! | #REF! | #REF! | #REF! | #REF! | #REF! | #REF! | #REF! | #REF! | #REF! | #REF!
PROMEDIO / TOTAL APROBADOS |  |  |  |  |  |  |  |  |  |  |  | 1 / 8 aprobados

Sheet: Criterios y Umbrales
CRITERIOS DE ACEPTACIÓN — CALIBRACIÓN uArm Metal
PARÁMETRO | NOMINAL | TOLERANCIA | APROBADO SI | ACCIÓN SI FALLA | REFERENCIA
LEFT_MAX (°) | 150 | ± 10° | 140 ≤ x ≤ 160 | Revisar límite mecánico o reemplazar servo LEFT | calibration.ino L43
RIGHT_MIN (°) | 20 | ± 10° | 10 ≤ x ≤ 30 | Revisar límite mecánico o reemplazar servo RIGHT | calibration.ino L44
R² ROT | ≥ 0.98 | — | R² ≥ 0.98 | Repetir calibración lineal. Verificar pin A2 | LinearRegression lr
R² LEFT | ≥ 0.98 | — | R² ≥ 0.98 | Repetir calibración lineal. Verificar pin A0 | LinearRegression lr
R² RIGHT | ≥ 0.98 | — | R² ≥ 0.98 | Repetir calibración lineal. Verificar pin A1 | LinearRegression lr
R² HAND | ≥ 0.95 | — | R² ≥ 0.95 | Algunos modelos sin feedback analógico en muñeca | LinearRegression lr
Offset ROT manual | 0° | ± 5° | |off| ≤ 5° | Reposicionar brazo en paso manual y repetir D4 | waitingForManualCalibration
Offset LEFT manual | 0° | ± 5° | |off| ≤ 5° | Reposicionar brazo en paso manual y repetir D4 | waitingForManualCalibration
Offset RIGHT manual | 0° | ± 5° | |off| ≤ 5° | Reposicionar brazo en paso manual y repetir D4 | waitingForManualCalibration
EEPROM escrita | 0x80 | — | Flag = 0x80 | Verificar conexión Arduino y repetir proceso completo | EEPROM.write(10, 0x80)

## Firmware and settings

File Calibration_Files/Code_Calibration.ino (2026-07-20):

/* 
===============================================================================
uArm Metal - Calibration Example

IMPORTANT:
Before compiling this example, install the official uArm Arduino library:
https://github.com/uArm-Developer/UArmForArduino

The library can be downloaded from GitHub and added to the Arduino IDE
using Sketch > Include Library > Add .ZIP Library, or by copying it into
your Arduino libraries folder.

===============================================================================

This example is for calibration on uArm.

1. Wait until you press the D7 button to start.
2. Automatically detects:
   - SERVO_LEFT maximum angle
   - SERVO_RIGHT minimum angle
3. Collects hundreds of points for each servo to calculate the linear regression.
4. Waits for you to manually move the uArm to the correct position to calibrate
   SERVO_ROT. Refer to:
   https://raw.githubusercontent.com/uArm-Developer/UArmForArduino/dev/examples/Metal/calibration.png
*/

#include "UFServo.h"
#include <EEPROM.h>
#include "linreg.h"
#define SERVO_ROT_NUM           0
#define SERVO_LEFT_NUM          1
#define SERVO_RIGHT_NUM         2
#define SERVO_HAND_ROT_NUM      3

#define SERVO_ROT_PIN           11
#define SERVO_LEFT_PIN          13
#define SERVO_RIGHT_PIN         12
#define SERVO_HAND_ROT_PIN      10

#define SERVO_ROT_ANALOG_PIN 2
#define SERVO_LEFT_ANALOG_PIN 0
#define SERVO_RIGHT_ANALOG_PIN 1
#define SERVO_HAND_ROT_ANALOG_PIN 3

// Calibration Flag & OFFSET EEPROM ADDRESS
#define CALIBRATION_FLAG                    10
#define CALIBRATION_LINEAR_FLAG             11
#define CALIBRATION_MANUAL_FLAG             12
#define CALIBRATION_STRETCH_FLAG            13

#define LINEAR_INTERCEPT_START_ADDRESS      70
#define LINEAR_SLOPE_START_ADDRESS          50
#define MANUAL_OFFSET_ADDRESS               30
#define OFFSET_STRETCH_START_ADDRESS        20
#define SERIAL_NUMBER_ADDRESS               100

#define CONFIRM_FLAG                        0x80

#define LIMIT_SW                2    // LIMIT Switch Button
#define BUZZER                  3    // HIGH = ON
#define BTN_D4                  4    // LOW = Pressed
#define BTN_D7                  7    // LOW = Pressed

#define PUMP_EN                 6    // HIGH = Valve OPEN
#define VALVE_EN                5    // HIGH = Pump ON


#define MAX_OFFSET_ANGLE            10
#define STANDARD_LEFT_MAX_ANGLE     150
#define STANDARD_RIGHT_MIN_ANGLE     20

void calibrate();
void alert(byte times, int runTime, int stopTime);
int getAverageAnalog(byte servo_number);

int current;         // Current state of the button
// (LOW is pressed b/c i'm using the pullup resistors)
long millis_held;    // How long the button was held (milliseconds)
long secs_held;      // How long the button was held (seconds)
long prev_secs_held; // How long the button was held in the previous check
byte previous = HIGH;
unsigned long firstTime; // how long since the button was first pressed


Servo leftServo;
Servo rightServo;
Servo rotServo;
Servo handServo;

int min_anagle = 90;
int left_init_pos = 90;
int right_init_pos = 90;
int analog_array[5]= {};
int angle_array[5]= {};
int left_max_angle = -1;
int right_min_angle = -1;

double linear_rot_a = 0.0f;
double linear_rot_b = 0.0f;

void setup() {
  Serial.begin(115200);
  pinMode(BUZZER, OUTPUT);
  pinMode(BTN_D4, INPUT_PULLUP);
  pinMode(BTN_D7, INPUT_PULLUP);
  Serial.println("[STEP]READY");
  Serial.println("[INFO]Waiting For Start, Please Press D7 to Start.");
}

void loop() {
  if (digitalRead(BTN_D7) == LOW) {

    delay(20);
    if (digitalRead(BTN_D7) == LOW)
    {
      Serial.println("[STEP]START");
      alert(2, 100, 100);
      delay(2000);
      Serial.println("[STEP]LIMITATION");
      get_limit_values();
      delay(500);
      Serial.println("[STEP]LINEAR");
      linear_calibration();
      delay(500);
      Serial.println("[STEP]MANUAL");
      delay(500);
      Serial.println("[INFO]Waiting For Manual Calibration, Please Press D4 Once Completed.");
      waitingForManualCalibration();
      delay(500);
      EEPROM.write(CALIBRATION_FLAG, CONFIRM_FLAG);
      delay(500);
      Serial.println("[STEP]COMPLETED");
      alert(1, 500, 500);
    }
  }
}

void waitingForManualCalibration() {
  while (true) {
    if (digitalRead(BTN_D4) == LOW) {

      delay(20);
      if (digitalRead(BTN_D4) == LOW)
      {
        alert(2, 100, 100);
        delay(2000);
        int analog = getAverageAnalog(SERVO_ROT_NUM);
        double rot_offset = linear_rot_b * analog + linear_rot_a - 45;
        double left_offset = left_max_angle - 150;
        double right_offset = right_min_angle - 20;
        Serial.print("[INFO]SERVO_ROT_OFFSET:");
        Serial.println(rot_offset);
        Serial.print("[INFO]SERVO_LEFT_OFFSET:");
        Serial.println(left_offset);
        Serial.print("[INFO]SERVO_ROT_OFFSET:");
        Serial.println(right_offset);
        save_manual_servo_offset(SERVO_ROT_NUM, rot_offset);
        delay(10);
        save_manual_servo_offset(SERVO_LEFT_NUM, left_offset);
        delay(10);
        save_manual_servo_offset(SERVO_RIGHT_NUM, right_offset);
        delay(10);
        save_manual_servo_offset(SERVO_HAND_ROT_NUM, 0);
        delay(10);
        EEPROM.write(CALIBRATION_MANUAL_FLAG, CONFIRM_FLAG);
        break;
      }
    }
  }
}

void get_limit_values() {
  //left servo
  Serial.println("[INFO]Trying to catch the limition for left & right servo");
  leftServo.attach(SERVO_LEFT_PIN);
  leftServo.write(left_init_pos);
  delay(1000);
  for (int p = left_init_pos; p <= 180; p += 1) { // goes from 0 degrees to 180 degrees
    // in steps of 1 degree
    leftServo.write(p);              // tell servo to go to position in variable 'pos'
    delay(50);                       // waits 15ms for the servo to reach the position
    Serial.print("[DEBUG]LEFT-");
    Serial.print(p);
    Serial.print(",");
    unsigned int dat[8], temp;
    unsigned char i = 0, j = 0;
    for (i = 0; i < 8; i++)
    {
      dat[i]= analogRead(SERVO_LEFT_ANALOG_PIN);

    }
    for (i = 0; i < 8; i++) { //BULB to get the most accuracy data
      for (j = 0; i + j < 7; j++) {
        if (dat[j]> dat[j + 1]) {
          temp = dat[j];
          dat[j]= dat[j + 1];
          dat[j + 1]= temp;
        }
      }
    }
    int val_analog = (dat[2]+ dat[3]+ dat[4]+ dat[5]) / 4;
    Serial.println(val_analog);
    int array_index = p % 5;
    analog_array[array_index]= val_analog;
    angle_array[array_index]= p;
    if (array_index == 4) {
      int average = 0;
      for (int k = 0; k < 3; k++) {
        average += analog_array[k + 1]- analog_array[k];
      }
      if (average <= 1) {
        left_max_angle = angle_array[0];
        break;
      }
    }

  }
  Serial.print("[INFO]Left_MAX_ANGLE:");
  Serial.println(left_max_angle);
  if (left_max_angle == -1) {
    left_max_angle = 180;
  }
  if (abs(left_max_angle - STANDARD_LEFT_MAX_ANGLE) > MAX_OFFSET_ANGLE) {
    alert(4, 100, 100);
  }
  else {
    alert(1, 300, 300);
  }
  leftServo.detach();
  delay(2000);
  //--------------------right servo------------------------
  for (int k = 0; k < 4; k++)
  {
    analog_array[k]= {0};
    angle_array[k]= {0};
  }
  rightServo.attach(SERVO_RIGHT_PIN);
  rightServo.write(right_init_pos);
  delay(1000);
  for (int p = right_init_pos; p >= 0; p -= 1) { // goes from 0 degrees to 180 degrees
    // in steps of 1 degree
    rightServo.write(p);              // tell servo to go to position in variable 'pos'
    delay(50);                       // waits 15ms for the servo to reach the position
    Serial.print("[DEBUG]RIGHT-");
    Serial.print(p);
    Serial.print(",");
    int val_analog = getAverageAnalog(SERVO_RIGHT_NUM);
    Serial.println(val_analog);
    int array_index = p % 5;
    analog_array[array_index]= val_analog;
    angle_array[array_index]= p;
    if (array_index == 0) {
      int average = 0;
      for (int k = 4; k > 1; k--) {
        average += analog_array[k]- analog_array[k - 1];
      }
      if (average <= 1) {
        right_min_angle = angle_array[4];
        break;
      }
    }

  }
  Serial.print("[INFO]Right_MIN_ANGLE:");
  Serial.println(right_min_angle);
  if (right_min_angle == -1) {
    right_min_angle = 0;
  }
  if (abs(right_min_angle - STANDARD_RIGHT_MIN_ANGLE) > MAX_OFFSET_ANGLE) {
    alert(4, 100, 100);
  }
  else {
    alert(1, 300, 300);
  }
  rightServo.detach();
}


/** Start Calibration all section
**/
void linear_calibration() {

  //        cleanEEPROM();
  for (int k = 0; k < 4; k++) {

    calibrate_linear_servo(k);
    delay(2000);
  }
  EEPROM.write(CALIBRATION_LINEAR_FLAG, CONFIRM_FLAG);
  //  //        manual_calibration_section();
  alert(1, 500, 500);
}

/** Calibrate each servo for linear offset
**/
void calibrate_linear_servo(byte servo_num)
{
  alert(1, 300, 300);
  double arr_real[90];
  double arr_input[90];
  int max_angle = 0;
  int min_angle = 0;
  switch (servo_num) {
    case SERVO_ROT_NUM:
      max_angle = 135;
      min_angle = 45;
      myattachServo(servo_num);
      setServoAngle(servo_num, min_angle);
      break;
    case SERVO_LEFT_NUM:
      max_angle = left_max_angle - 5;
      min_angle = left_max_angle - 90 + 5;
      myattachServo(servo_num);
      setServoAngle(servo_num, min_angle);
      break;
    case SERVO_RIGHT_NUM:
      min_angle = right_min_angle + 5;
      max_angle = right_min_angle + 90 - 5;
      myattachServo(servo_num);
      setServoAngle(servo_num, min_angle);
      break;
    case SERVO_HAND_ROT_NUM:
      max_angle = 135;
      min_angle = 45;
      myattachServo(servo_num);
      setServoAngle(servo_num, min_angle);
      break;
  }
  delay(1000);
  for (byte i = 0, angle = min_angle ; angle < max_angle; i ++, angle++) {
    setServoAngle(servo_num, angle);
    delay(100);
    arr_input[i]= angle;
    arr_real[i]= getAverageAnalog(servo_num);
    Serial.print("[DEBUG]SERVO_ANGLE_");
    Serial.print(servo_num);
    Serial.print(": ");
    Serial.print(angle);
    Serial.print(", Analog: ");
    Serial.println(arr_real[i]);
  }
  setServoAngle(servo_num, 90);
  delay(1000);
  mydetachServo(servo_num);




  LinearRegression lr(arr_real, arr_input, 90);
  if (servo_num == SERVO_ROT_NUM) {
    linear_rot_a = lr.getA();
    linear_rot_b = lr.getB();
  }
  Serial.print("[INFO]lr.getA():");
  Serial.println(lr.getA());
  Serial.print("[INFO]lr.getB():");
  Serial.println(lr.getB());
  save_linear_servo_offset(servo_num, lr.getA(), lr.getB());
}

void setServoAngle(byte servo_number, byte angle) {
  switch (servo_number) {
    case SERVO_ROT_NUM:
      rotServo.write(angle);
      break;
    case SERVO_LEFT_NUM:
      leftServo.write(angle);
      break;
    case SERVO_RIGHT_NUM:
      rightServo.write(angle);
      break;
    case SERVO_HAND_ROT_NUM:
      handServo.write(angle);
      break;
  }
}

int getAverageAnalog(byte servo_number) {
  byte analog_pin;
  switch (servo_number) {
    case SERVO_ROT_NUM:
      analog_pin = SERVO_ROT_ANALOG_PIN;
      break;
    case SERVO_LEFT_NUM:
      analog_pin = SERVO_LEFT_ANALOG_PIN;
      break;
    case SERVO_RIGHT_NUM:
      analog_pin = SERVO_RIGHT_ANALOG_PIN;
      break;
    case SERVO_HAND_ROT_NUM:
      analog_pin = SERVO_HAND_ROT_ANALOG_PIN;
      break;
  }
  unsigned int dat[8], temp;
  unsigned char i = 0, j = 0;
  for (i = 0; i < 8; i++)
  {
    dat[i]= analogRead(analog_pin);

  }
  for (i = 0; i < 8; i++) { //BULB to get the most accuracy data
    for (j = 0; i + j < 7; j++) {
      if (dat[j]> dat[j + 1]) {
        temp = dat[j];
        dat[j]= dat[j + 1];
        dat[j + 1]= temp;
      }
    }
  }
  int val_analog = (dat[2]+ dat[3]+ dat[4]+ dat[5]) / 4;
  return val_analog;
}

void myattachServo(byte servo_number) {
  switch (servo_number) {
    case SERVO_ROT_NUM:
      if (!rotServo.attached()) {
        rotServo.attach(SERVO_ROT_PIN);
      }
      break;
    case SERVO_LEFT_NUM:
      if (!leftServo.attached()) {
        leftServo.attach(SERVO_LEFT_PIN);
      }
      break;
    case SERVO_RIGHT_NUM:
      if (!rightServo.attached()) {
        rightServo.attach(SERVO_RIGHT_PIN);
      }
      break;
    case SERVO_HAND_ROT_NUM:
      if (!handServo.attached()) {
        handServo.attach(SERVO_HAND_ROT_PIN);
      }
      break;
  }
}

void mydetachServo(byte servo_number) {
  switch (servo_number) {
    case SERVO_ROT_NUM:
      rotServo.detach();
      break;
    case SERVO_LEFT_NUM:
      leftServo.detach();
      break;
    case SERVO_RIGHT_NUM:
      rightServo.detach();
      break;
    case SERVO_HAND_ROT_NUM:
      handServo.detach();
      break;
  }
}

void alert(byte times, int runTime, int stopTime)
{
  for (int ct = 0; ct < times; ct++)
  {
    delay(stopTime);
    digitalWrite(BUZZER, HIGH);
    delay(runTime);
    digitalWrite(BUZZER, LOW);
  }
}

/** Save Manual Servo Offset

**/
void save_manual_servo_offset(byte servo_num, double offset)
{
  EEPROM.put(MANUAL_OFFSET_ADDRESS + servo_num * sizeof(offset), offset);
}

/** Save Linear Servo Offset intercept & slope
**/
void save_linear_servo_offset(byte servo_num, double intercept_val, double slope_val) {
  EEPROM.put(LINEAR_INTERCEPT_START_ADDRESS + servo_num * sizeof(intercept_val), intercept_val);
  EEPROM.put(LINEAR_SLOPE_START_ADDRESS + servo_num * sizeof(slope_val), slope_val);
}
